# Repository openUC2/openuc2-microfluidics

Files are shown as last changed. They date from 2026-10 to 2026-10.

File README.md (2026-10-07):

# openUC2 microfluidics

Parametric microfluidic chips for openUC2 microscopes. Each chip is built by a Python script as
**native Autodesk Inventor parts** (`.ipt`) and an assembly (`.iam`). The script talks to Inventor
over COM (pywin32, the PyInventor toolchain). Every dimension ends up as an Inventor user
parameter, and the script also exports STEP and print-ready STL files.

| chip | folder | |
|---|---|---|
| Leaf chamber | [`chips/leaf_chamber`](chips/leaf_chamber/README.md) | slide-format perfusion chamber for a leaf sample: screw plug with O-ring (optional window), luer-lock inlet, luer (B, default) or reservoir (A) outlet, glued bottom coverslip |

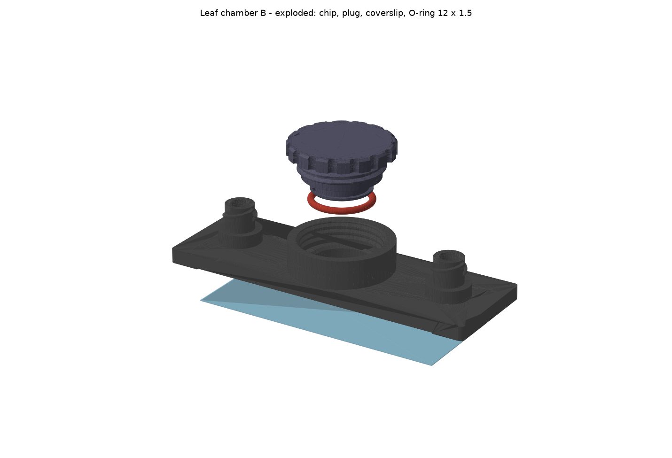
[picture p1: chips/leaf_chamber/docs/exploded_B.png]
leaf chamber


## Layout

```
mfcad/                      shared library
  params.py                 parameter tables: base values + derived expressions, valid both in
                            Python (checks, initial geometry) and as Inventor expressions
  native_part.py            NativePart: sketches dimensioned against parameter expressions,
                            extrudes, coils (threads, lugs), patterns, fillets, chamfers,
                            health report, AP214 STEP and STL export, reading parameters back
  stock_parts.py            bought glass parts that openUC2-CAD-new lacks (coverslips)
  inventor_helpers.py       the shared openUC2 builder helper (session, CAD-new lookup, Builder) -
                            identical copy of openuc2-opmsimulator / openuc2-openraman, keep in sync
chips/<chip>/
  <chip>.py                 parameters, variants, design checks (plain Python)
  build_<chip>.py           Inventor builder: parts, assembly, interference check, STEP/STL
  check_<chip>.py           independent checks on the STEP exports + figures for docs/
  INVENTOR/                 generated .ipt/.iam/.stp/.stl and "<part> - params.json"
  docs/                     figures
```

## Environments

- **Inventor builds:** `C:\Users\benir\miniforge3\envs\pyinventor\python.exe` with Inventor 2025
  running. The session helper restores `SilentOperation` and closes only the documents the script
  opened.
- **Checks and figures:** `uv run --with cadquery --with trimesh --with rtree --with scipy --with shapely --with networkx --with matplotlib python check_<chip>.py`.
- **Parameter tables and design checks:** any Python 3.10+ (`python <chip>.py`).

## Adding a chip

1. Copy `chips/leaf_chamber` to `chips/<new_chip>` and rename the three scripts.
2. In `<chip>.py`, declare the knobs with `P(name, value, unit, comment)` and the derived values
   with `D(name, "expression", ...)`. Write expressions as plain arithmetic of parameter names,
   with units on literal numbers (`0.3 mm`). Write the design checks.
3. In `build_<chip>.py`, describe the features with `NativePart`, always in parameter expressions:
   `part.circle(s, "-out_x", 0, "res_d", ...)`, `part.extrude(s, "res_top - res_floor", kNeg, kCut, ...)`.
   Parameters are created in the part on first use, so each part carries only what it needs.
4. Names follow openUC2-CAD-new (`PRT - 9xxx - <ABBREV> - V04 - <variant>`, `BUY - ...`). Use
   CAD-new parts where they exist; the O-rings come from `STD/ISO 3601-1 - O-rings`.
   Provisional numbers: 9300–9302 are taken by the leaf chamber.

Frame convention used so far: z = 0 on the glue plane (top of the bottom coverslip = sample
plane), chamber centre at the origin, inlet towards +X.

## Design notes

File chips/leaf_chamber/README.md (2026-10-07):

# Leaf chamber chip (slide format, screw-sealed, luer perfusion)

A 75 × 25 mm chip for transmission microscopy of a piece of leaf that is perfused by a pump:
water, H₂O₂ or another solution goes in through a female **luer lock**, flows through the
chamber past the leaf, and leaves into an open **reservoir** (variant A) or a second **luer**
(variant B, the default). The leaf chamber is closed with a **3D-printed screw plug** that carries an
O-ring. The plug is solid by default (`plug_window = 0`); with `plug_window = 1` it gets a glued
glass window and a clear aperture, so the sample sits between two coverslips.

exploded

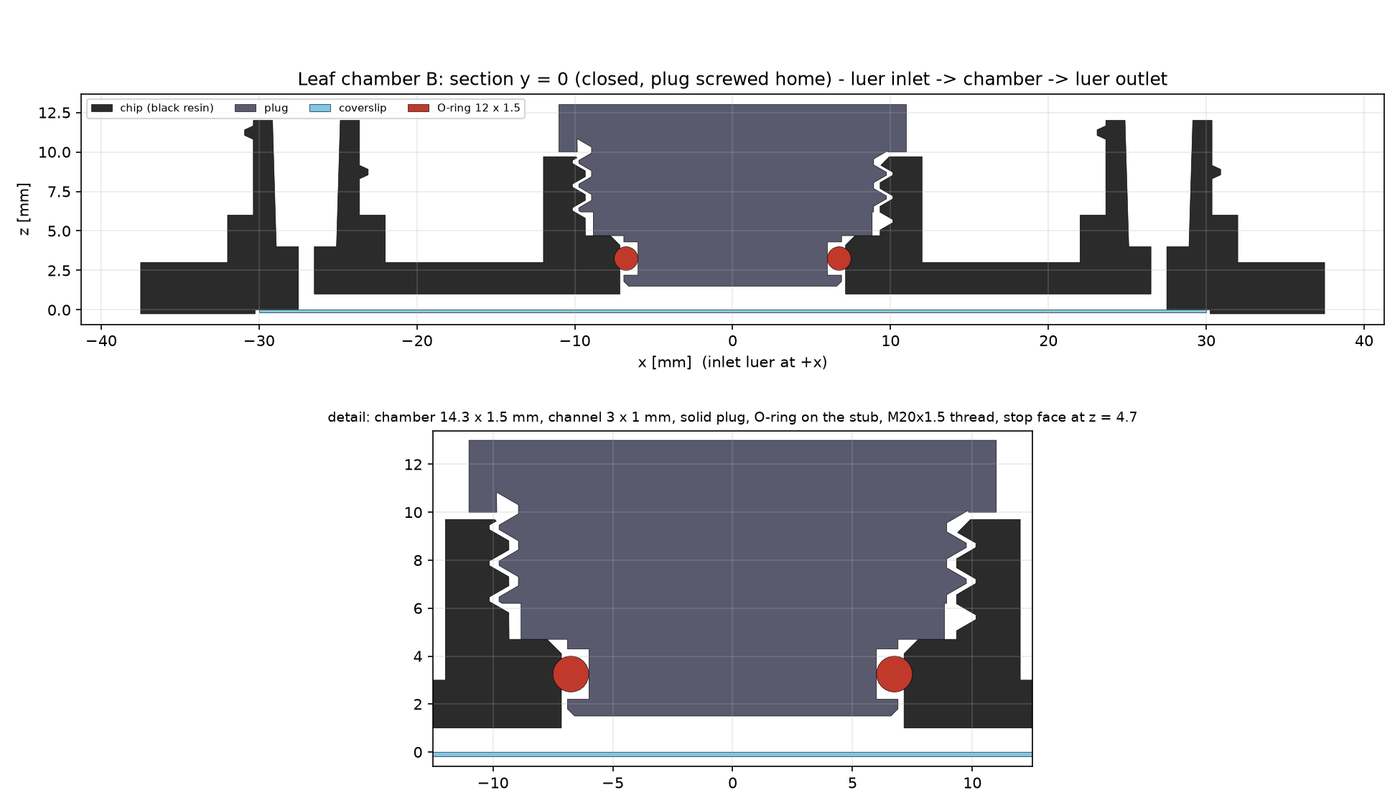
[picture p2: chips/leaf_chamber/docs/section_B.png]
section


| variant | outlet | chip | assembly |
|---|---|---|---|
| B (default) | luer lock (tubing) | `PRT - 9301 - MFLEAFCHIP - V04 - B` | `ASS - 9300 - MFLEAF - V04 - B` |
| A | open reservoir, 1.5 mL | `PRT - 9301 - MFLEAFCHIP - V04 - A` | `ASS - 9300 - MFLEAF - V04 - A` |

Both use the same plug `PRT - 9302 - MFLEAFPLUG - V04`. The numbers are provisional (9xxx is
unused in openUC2-CAD-new); renumber them in `leaf_chamber.py` (`NUMBERS`).

## Create

```
C:\Users\benir\miniforge3\envs\pyinventor\python.exe build_leaf_chamber.py --variant B --set ch_w=3 --set chamber_h=2.0 --set th_clear=.3 --set stub_clear=.3
C:\Users\benir\miniforge3\envs\pyinventor\python.exe build_leaf_chamber.py --set ch_w=3 --set ch_h=1.0 --set chamber_h=1.5
```

## How it works

- **Optical floor and channel lid in one.** The channels are open grooves on the underside of the
  chip. A 24 × 60 mm #1.5 coverslip is glued into a 0.25 mm deep band under the chip. It closes the
  channels and is also the floor the leaf lies on. Open grooves print crisp on the Form 4 and wash
  out easily; closed SLA channels below about 0.5 mm tend to clog with uncured resin. To get closed
  tunnels instead, set `ch_floor > 0` (see "Variants of the idea").
- **Chamber.** A Ø14.3 well through the slab. The leaf lies on the coverslip, and the chamber is
  `chamber_h` high (0.8 mm by default, about 128 µL). The channels enter the well at floor level,
  so a channel can be at most as deep as the chamber (`ch_floor + ch_h <= chamber_h`).
- **Plug.** The plug is M20 × 1.5 with modelled threads, right-handed. The printing clearance is
  split: `th_clear` (chip bore) and `plug_th_clear` (plug), so the fit can be loosened by reprinting
  only the plug. Its stub reaches into the well:
  - The stub bottom is the **chamber ceiling**. A solid black plug blocks the transmitted light:
    print it in Clear resin, or set `plug_window = 1` for a Ø12 #1.5 round coverslip glued into the
    stub plus a Ø10 aperture.
  - The stub carries the CAD-new **O-ring ISO 3601-1 12 × 1.5**. It forms a static radial seal
    against the well bore: 23 % squeeze, 73 % groove fill.
  - The plug **bottoms out on a stop face** (`ledge_z`). The chamber height therefore does not
    depend on how hard you screw, and the seal does not depend on torque.
  - The head has 16 grip flutes.
- **Ports.** Female luer lock to ISO 80369-7 / ISO 594-2:
  - 6 % taper bore, Ø4.29 at the face, 8 mm deep
  - Ø6.73 hub, two right-hand lugs to Ø7.83 (2-start, 5 mm lead)
  - the hub stays slim for 6 mm below the face for the male collar, on a Ø10 foot

  A Ø1 via connects each port to its channel.

Frame (all parts share it, so the assembly places everything at identity): origin at the chamber
centre on the glue plane, so z = 0 is the top of the bottom coverslip (the leaf plane). The inlet
is at +X, the outlet at −X, and Z points away from the objective (inverted microscope). Overall
height above the coverslip is `plug_top` (12.3 mm by default, 13 mm with `chamber_h = 1.5`) and
12 mm at the luer.

## Build

Needs a running Inventor and the miniforge `pyinventor` env (pywin32):

```bash
cd chips\leaf_chamber
python leaf_chamber.py                          # parameter table + design checks only (no Inventor)
C:\Users\benir\miniforge3\envs\pyinventor\python.exe build_leaf_chamber.py           # variant B (default)
C:\Users\benir\miniforge3\envs\pyinventor\python.exe build_leaf_chamber.py --set ch_w=3 --set ch_h=1.0 --set chamber_h=1.5
C:\Users\benir\miniforge3\envs\pyinventor\python.exe build_leaf_chamber.py --variant all   # A and B
C:\Users\benir\miniforge3\envs\pyinventor\python.exe build_leaf_chamber.py --params my_chip.json --show
```

Outputs go to `INVENTOR/`:
- the parts `.ipt` and the assemblies `.iam`;
- `.stp` files (AP214, with colours);
- `.stl` files of the two printed parts, in mm, at Inventor's "High" resolution (under 5 µm chord error);
- `<chip> - params.json` with every parameter, the check results and the build report.

The builder runs the design checks first and refuses parameters that break the design, for
example an O-ring squeeze outside 15–32 %, ports off the coverslip, a channel the stub would
block, or walls that are too thin. It then runs Inventor's interference analysis on the closed
assembly. The only overlap there is the intended O-ring squeeze, 14.4 mm³ against the well bore.

### Changing dimensions

Every dimension is an **Inventor user parameter** of the part (Manage → fx). The derived ones are
Inventor expressions, such as `th_bore_d = th_d - 1.0825 * th_p + 2 * th_clear`. So you can open
the `.ipt`, change `ch_w`, `well_d`, `in_x`, `th_p`, `luer_lug_rev`, and so on, and the feature
tree follows, threads and luer lugs included. This was tested: 15 parameter sets on chip and plug,
all features healthy.

Keep in mind:
- **Chip and plug are separate files.** Parameters they share (`well_d`, `chamber_h`, `stub_len`,
  `th_*`, `th_len`) must be changed in both. The script does that for you.
- **To bring Inventor edits back into the script:** run
  `build_leaf_chamber.py --variant A --from-ipt "INVENTOR\PRT - 9301 - MFLEAFCHIP - V04 - A.ipt"`.
  It reads the part's base parameters and rebuilds everything consistently.
- **Couplings that the checks watch:**
  - `well_d` with `groove_root_d` and `oring_cs` (squeeze);
  - `ch_floor + ch_h ≤ chamber_h`;
  - the ports must lie at least 2 mm inside the coverslip (`cs_l`).
  - `chamber_h` raises the stop face (`ledge_z = chamber_h + stub_len`) and the boss top
    (`boss_top = ledge_z + th_len`), so the plug geometry stays valid.

The knobs you are most likely to turn:

| parameter | default | |
|---|---|---|
| `ch_w`, `ch_h` | 1.0, 0.5 mm | channel width and depth; `ch_h` at most `chamber_h` |
| `ch_floor` | 0 | 0 = open groove under the coverslip; > 0 = closed tunnel |
| `via_d` | 1.0 mm | vertical via into the ports; up to about 2.5 (taper bottom Ø3.8) for wide channels |
| `well_d`, `chamber_h` | 14.3, 0.8 mm | leaf space; the O-ring seals on `well_d` |
| `oring_id`, `oring_cs` | 12, 1.5 mm | O-ring size; the groove follows `groove_root_d` (about `well_d - 1.55 * oring_cs`) and `groove_w` (about 1.4 × `oring_cs`) |
| `plug_th_clear` | 0.25 mm | plug thread clearance, radial per side; raise it if the plug is tight |
| `th_clear` | 0.15 mm | chip bore thread clearance, radial per side |
| `stub_clear` | 0.25 mm | stub-to-well clearance, radial per side (plug only) |
| `th_d`, `th_p` | 20, 1.5 mm | thread size; a coarser `th_p` allows more clearance |
| `plug_window` | 0 | 1 = glued window `win_d` (12) with aperture `win_ap` (10) |
| `in_x`, `out_x` | 27, 27 (B) / 25 (A) mm | port positions from the chamber centre |
| `cs_l`, `cs_w`, `cs_t`, `cs_recess` | 60, 24, 0.17, 0.25 mm | bottom coverslip and its glue band |
| `res_d`, `res_top` | 16, 9 mm | reservoir (A) |
| `luer_open_d`, `luer_lug_rev` | 4.29 mm, 0.5 | luer fit and lug length |

`python leaf_chamber.py` prints the whole table with comments.

## Verification

`check_leaf_chamber.py` works on the exported STEP files, independently of Inventor. It
samples points in the mesh domain, because Inventor STEPs break OCC booleans. It checks:
- the internal thread, the plug thread and both luer lugs are **right-handed**, so a standard
  male luer locks on;
- the plug ridges sit in the boss grooves when closed (0 of 17,280 samples overlap);
- the fluid path is open from via to via along the channel, and the channel walls are closed;
- the vias and luer bores are open;
- the open channels lie on the coverslip.

It also draws `docs/section_*.png`, `docs/plan_*.png` and `docs/exploded_*.png`.

```bash
uv run --with cadquery --with trimesh --with rtree --with scipy --with shapely --with networkx --with matplotlib python check_leaf_chamber.py
```

## Print (Form 4, Black resin)

- **Chip:** put the glue face (the side with the channels) **up**, away from the platform. That
  keeps the channels and the glue band support-free and sharp, and the supports land on the boss,
  luer and reservoir tops. A 10–15° tilt helps against cupping in the well and reservoir; check
  PreForm's cup warnings. Do not print the glue face flat on the platform: first-layer over-cure
  closes 0.5 mm grooves.
- **Plug:** put the head toward the platform, thread axis vertical. The window recess and O-ring
  groove stay support-free.
- **Fit:** if the plug runs tight, raise `plug_th_clear` (thread) or `stub_clear` (stub in the
  well) and reprint only the plug. If it gets tight only when the O-ring enters the well, it is the
  O-ring squeeze: grease it, or lower the squeeze with a smaller `groove_root_d`. Wash the open channels well, then post-cure fully. Uncured monomer is not good for
  living tissue.

## Assemble and use

1. Glue the 24 × 60 coverslip into the band. Keep the adhesive out of the channels: thin UV glue
   (for example NOA 81) applied away from the grooves, or a double-sided transfer tape with the
   channel cut out. Cure, then check by flushing.
2. With `plug_window = 1` only: glue the Ø12 round coverslip into the stub recess from below.
3. Fit the O-ring on the stub. A trace of silicone grease or water makes screwing smooth.
4. Put the leaf piece (up to about Ø14, at most about 0.6 mm thick for `chamber_h` = 0.8) on the
   bottom coverslip in the well.
5. Screw the plug in by hand until it stops on the stop face.
6. Connect the pump with a male luer lock to the inlet (+X). Variant A fills the reservoir; it can
   also be used the other way round, with the pump pulling liquid from the reservoir.

Bill of materials per chip:
- printed chip and plug (Black resin);
- coverslip 24 × 60 mm #1.5;
- round coverslip Ø12 mm #1.5 (only with `plug_window = 1`);
- O-ring 12 × 1.5 (ISO 3601-1). CAD-new has it in NBR70; for **H₂O₂** use EPDM or FKM in the same
  size, because NBR is attacked by oxidisers;
- adhesive or transfer tape.

## Open points

- **Coverslip size.** "60 × 40 mm" cannot sit under a 25 mm wide slide, so the default is the
  standard **24 × 60**, which covers every open channel and via. A 24 × 40 coverslip only works
  with closed channels: `--set cs_l=40 --set ch_floor=0.3 --set ch_h=0.5 --set chamber_h=1.0`
  passes the checks.
- **Bubbles.** Leaf tissue (catalase) turns H₂O₂ into O₂. Bubbles collect under the flat window, so
  a higher flow rate helps to carry them to the outlet.
- **Luer lugs.** The printed lugs are 0.55 mm high, as in ISO. If they wear out, a glue-in
  commercial female luer would be a small new variant.
- **Microscope clearance.** Check the 12.3 mm build height against the condenser or LED.

Sources for the luer dimensions: [ISO 594-2 summary (Uni Bremen)](https://www.sedgeochem.uni-bremen.de/luer%20connector.html),
lug and opening tolerances as cited in [US patent 11235134](https://image-ppubs.uspto.gov/dirsearch-public/print/downloadPdf/11235134).

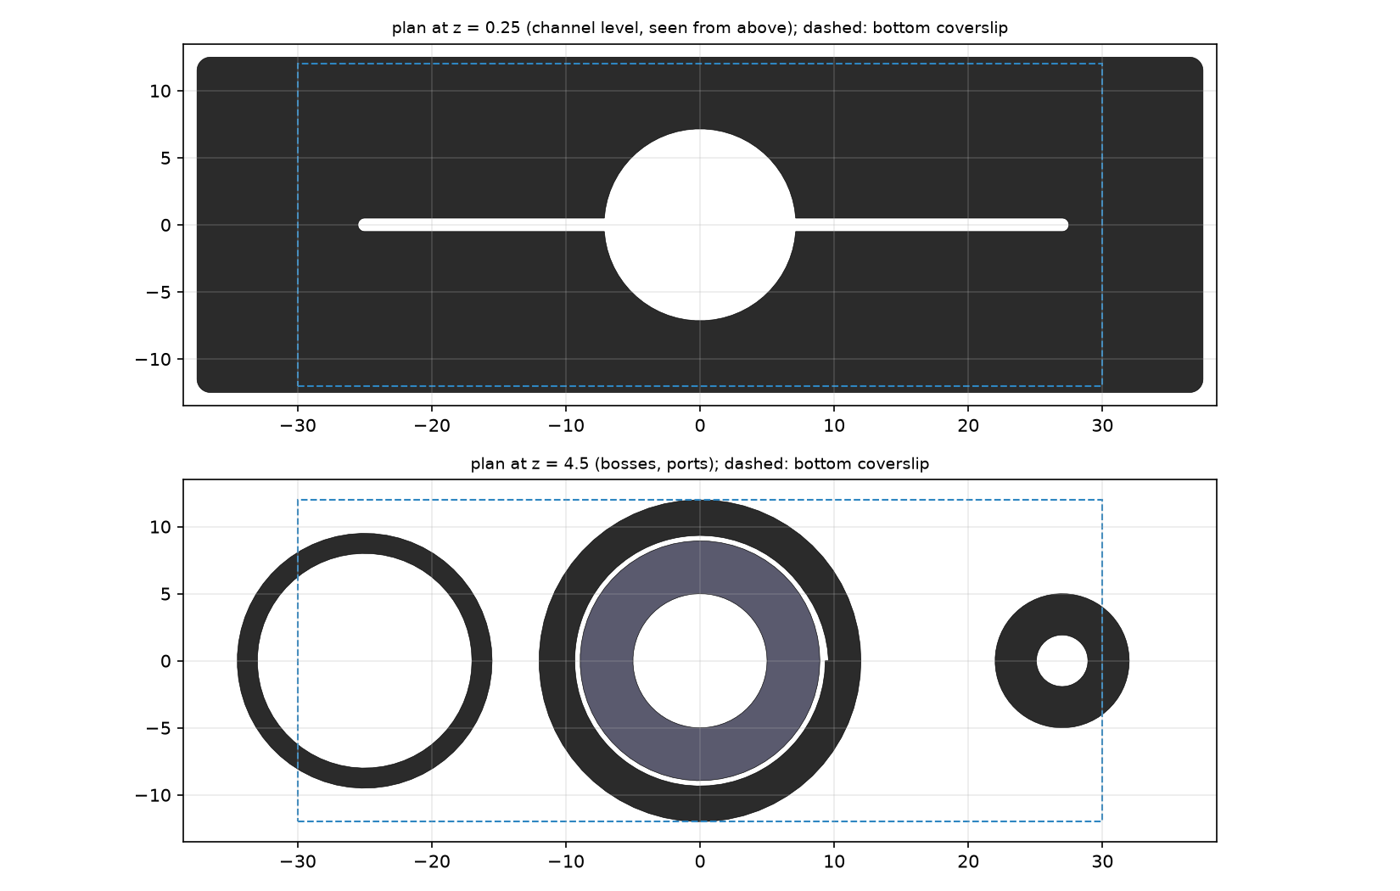
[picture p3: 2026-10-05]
chips/leaf_chamber/docs/plan_A.png

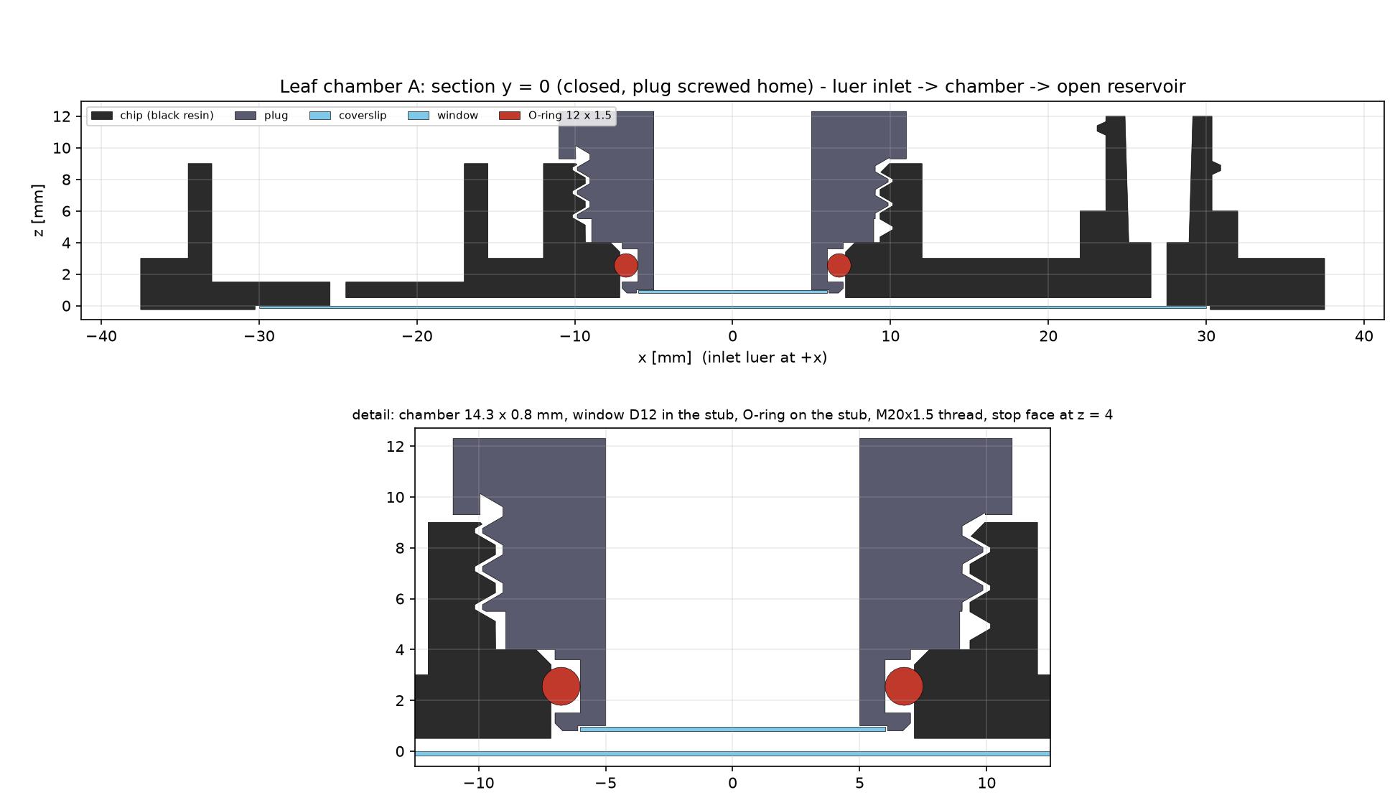
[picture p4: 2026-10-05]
chips/leaf_chamber/docs/section_A.png

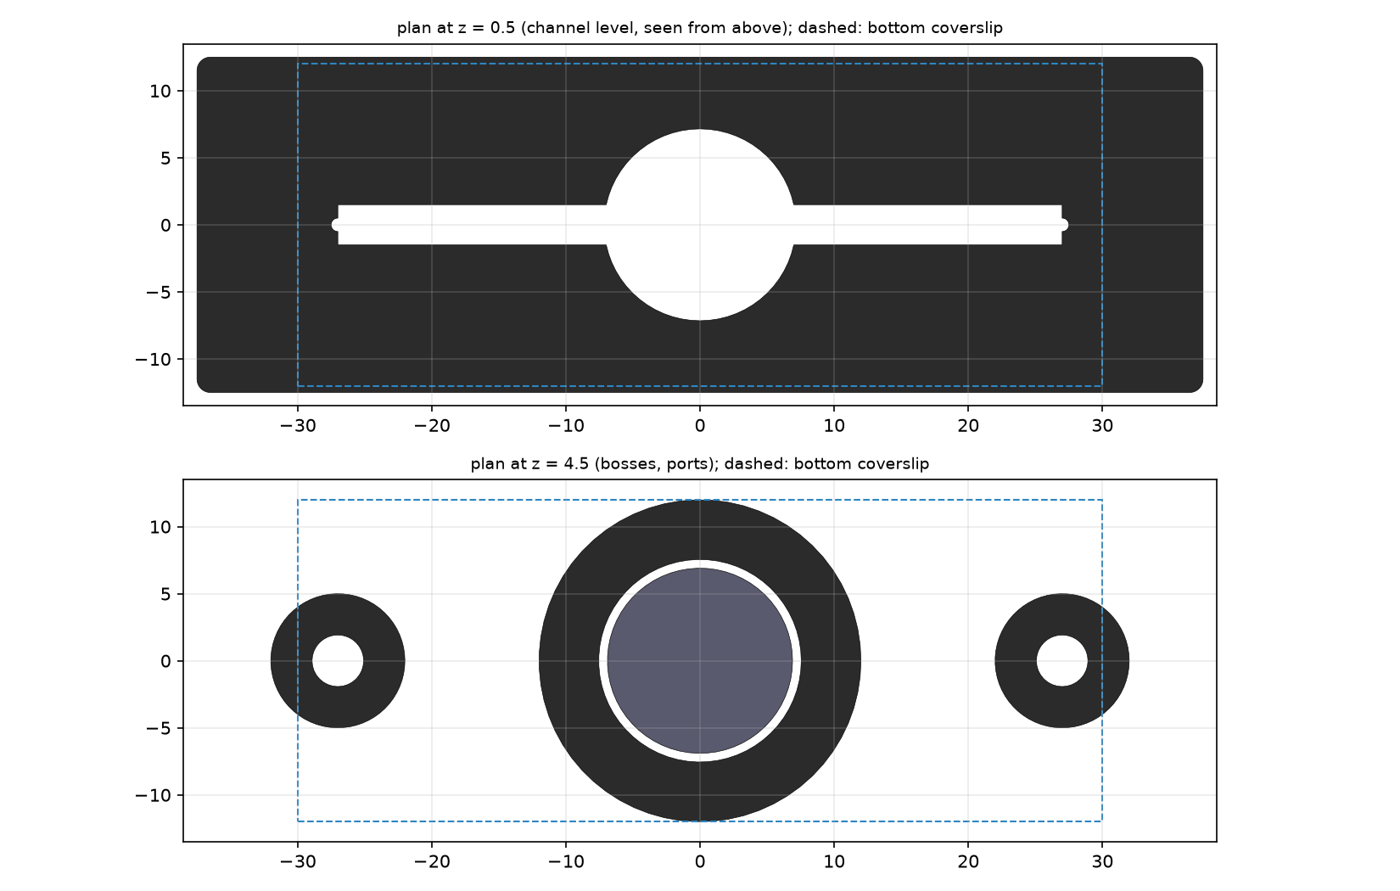
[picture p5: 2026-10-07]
chips/leaf_chamber/docs/plan_B.png

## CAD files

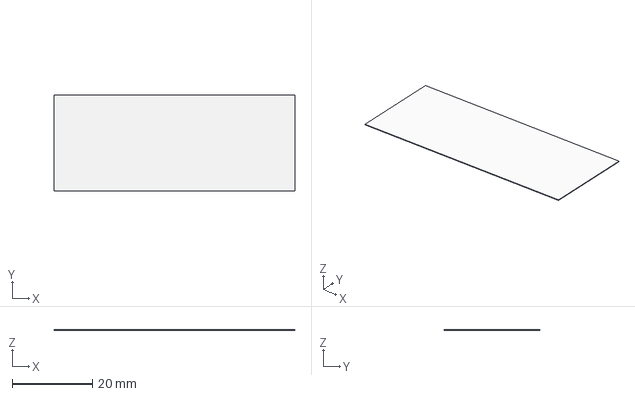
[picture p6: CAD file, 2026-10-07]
chips/leaf_chamber/INVENTOR/BUY - Cover glass - 24 x 60 x 0.17.stp
60.0 x 24.0 x 0.17 mm

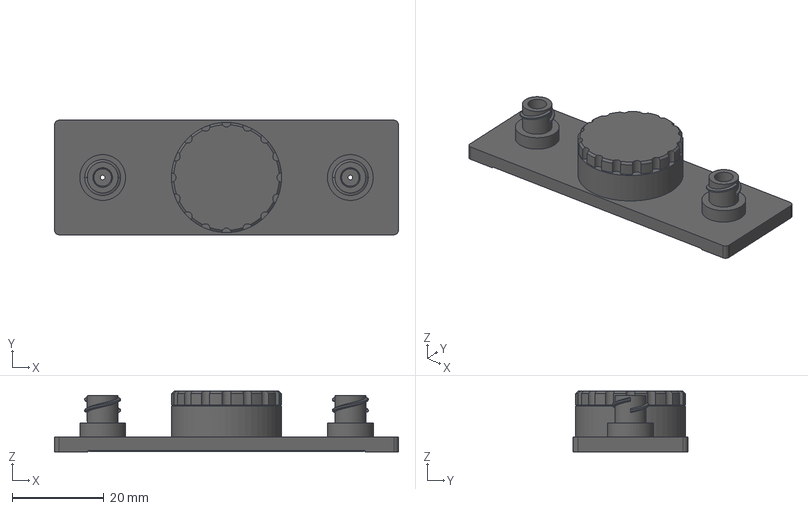
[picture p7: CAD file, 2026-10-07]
chips/leaf_chamber/INVENTOR/ASS - 9300 - MFLEAF - V04 - B.stp
75.0 x 25.0 x 13.2 mm
PRT - 9301 - MFLEAFCHIP - V04 - B
PRT - 9302 - MFLEAFPLUG - V04
BUY - Cover glass - 24 x 60 x 0.17
ISO 3601-1 - O-ring - 12 x 1.5 - NBR70

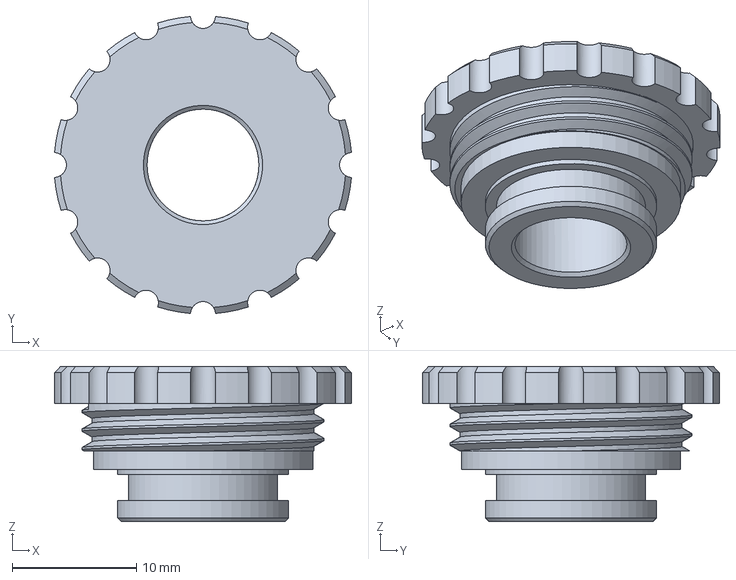
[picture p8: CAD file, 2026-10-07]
chips/leaf_chamber/INVENTOR/PRT - 9302 - MFLEAFPLUG - V04.stp
23.9 x 23.9 x 12.5 mm

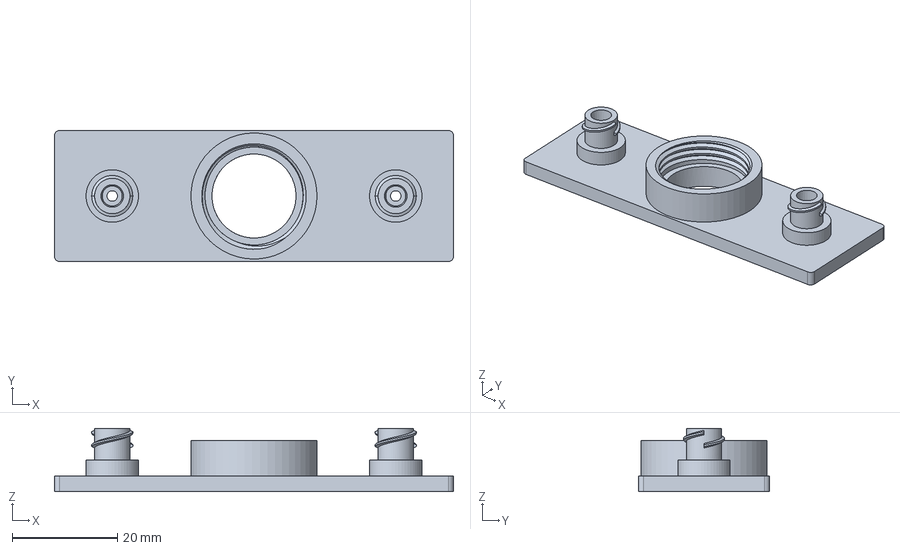
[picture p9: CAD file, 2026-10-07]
chips/leaf_chamber/INVENTOR/PRT - 9301 - MFLEAFCHIP - V04 - B.stp
76.0 x 25.0 x 12.0 mm

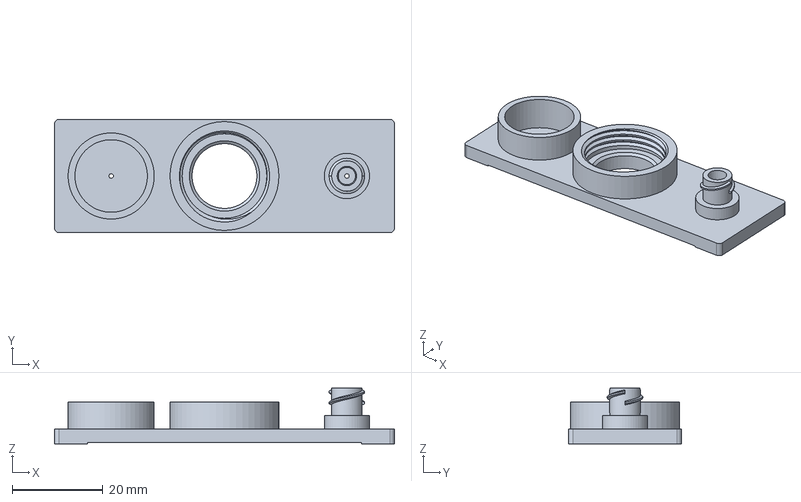
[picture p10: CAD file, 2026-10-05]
chips/leaf_chamber/INVENTOR/PRT - 9301 - MFLEAFCHIP - V04 - A.stp
75.0 x 25.0 x 12.2 mm

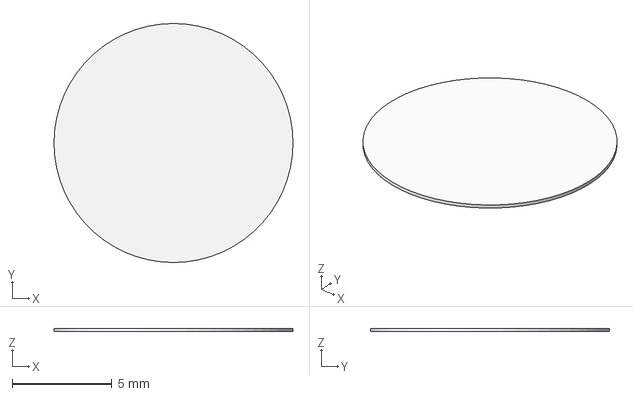
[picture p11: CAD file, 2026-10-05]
chips/leaf_chamber/INVENTOR/BUY - Cover glass - D12 x 0.17.stp
12.0 x 12.0 x 0.17 mm

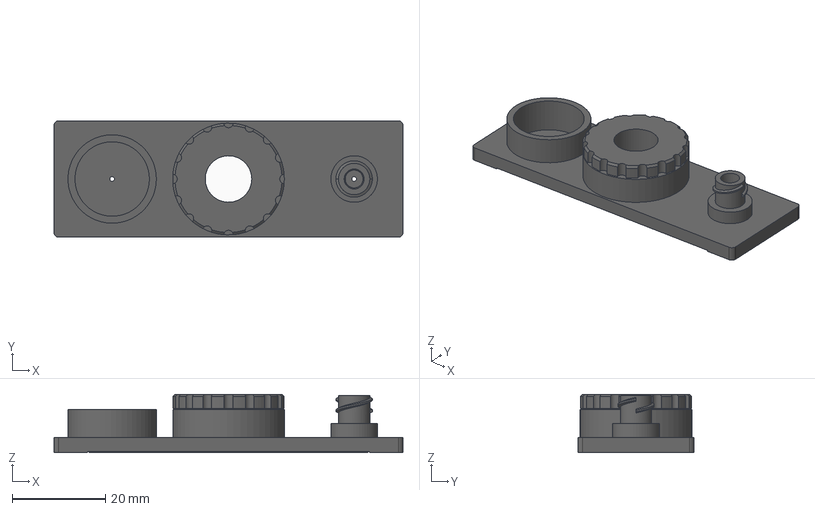
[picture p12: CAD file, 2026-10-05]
chips/leaf_chamber/INVENTOR/ASS - 9300 - MFLEAF - V04 - A.stp
75.0 x 25.0 x 12.6 mm
PRT - 9301 - MFLEAFCHIP - V04 - A
PRT - 9302 - MFLEAFPLUG - V04
BUY - Cover glass - 24 x 60 x 0.17
BUY - Cover glass - D12 x 0.17
ISO 3601-1 - O-ring - 12 x 1.5 - NBR70

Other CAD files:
chips/leaf_chamber/INVENTOR/ASS - 9300 - MFLEAF - V04 - A.iam
chips/leaf_chamber/INVENTOR/ASS - 9300 - MFLEAF - V04 - B.iam
chips/leaf_chamber/INVENTOR/BUY - Cover glass - 24 x 60 x 0.17.ipt
chips/leaf_chamber/INVENTOR/BUY - Cover glass - D12 x 0.17.ipt
chips/leaf_chamber/INVENTOR/PRT - 9301 - MFLEAFCHIP - V04 - A.ipt
chips/leaf_chamber/INVENTOR/PRT - 9301 - MFLEAFCHIP - V04 - A.stl
chips/leaf_chamber/INVENTOR/PRT - 9301 - MFLEAFCHIP - V04 - B.ipt
chips/leaf_chamber/INVENTOR/PRT - 9301 - MFLEAFCHIP - V04 - B.stl
chips/leaf_chamber/INVENTOR/PRT - 9302 - MFLEAFPLUG - V04.ipt
chips/leaf_chamber/INVENTOR/PRT - 9302 - MFLEAFPLUG - V04.stl
